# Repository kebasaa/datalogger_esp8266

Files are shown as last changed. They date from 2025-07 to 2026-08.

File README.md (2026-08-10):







# Asynchronous datalogger using ESP8266

Asynchronous datalogger using ESP8266 for logging scientific sensors to MicroSD

## Offline dashboard

The firmware starts a protected setup access point when it has no saved Wi-Fi
credentials and, after a 30-second station outage, exposes the dashboard again
through that access point. Change `HOTSPOT_PASSWORD`, `DASHBOARD_USER` and
`DASHBOARD_PASSWORD` in `src/main.cpp` before deployment.

Open `http://192.168.4.1/` on the access point, or the logger's address on your
network. The dashboard has four tabs:

- **Status** — whether the logger is actually recording, GPS fix and time
  quality, battery, free heap, MicroSD space and write errors, per-bus I2C
  health and the supervisor counters. Updates once a second.
- **Calibration** — sessions, live raw versus calibrated readings, zero/span
  and differential calibration, and the stored coefficients.
- **WiFi** — scan for networks and join one.
- **Console** — runs the same commands as the serial port, for when something
  needs poking at and no cable is to hand.

It is a small single-page app served from the logger's own flash: no internet
connection is needed and nothing is loaded from a CDN. It scales from a phone
in the field to a desktop browser, and follows your system's light or dark
theme (with a toggle to override).

> The web interface lives in `web/src/`. A pre-build script minifies and gzips
> it into `data/h4/`, so after changing it you must upload the filesystem as
> well as the firmware:
>
> ```bash
> pio run -e d1_mini_pro -t upload -t uploadfs
> ```

GPS is connected directly to the I2C bus. Its reader is deliberately separate
from the TCA9548A channels; do not pass the multiplexer to the GPS constructor
unless the hardware wiring changes.

Sensor & logger testing in the field

<p align="center">
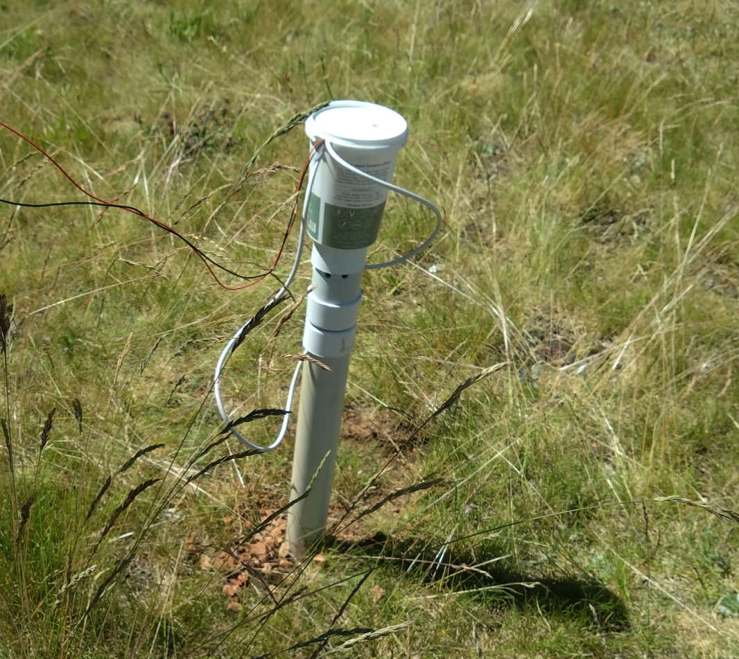
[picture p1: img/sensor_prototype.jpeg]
Prototype testing
  
</p>

## Serial commands

The web interface has no private channel to the firmware: every button on it
runs one of the commands below, over `GET /rest/<command>/<parameters>`. So
anything the dashboard can do can also be done from the serial port or with
`curl`, which is what you want when no Wi-Fi is available, when calibrating
from a script, or when a logger needs rescuing.

### Connecting

Connect at **115200 baud** (`monitor_speed` in `platformio.ini`; the firmware
takes the same value through `PROJ_BAUD_RATE`):

```bash
pio device monitor -e d1_mini_pro
```

Type a command and press Enter. Parameters are separated by a forward slash,
with no spaces:

```
command/parameter/parameter/...
```

Commands are case-sensitive. `help` lists every command the firmware knows,
including the built-in H4 ones described at the end of this section.

### Overview

| Command | Parameters | Needs a session | What it does |
| --- | --- | --- | --- |
| `cal_start` | none | – | Starts a calibration session |
| `cal_stop` | none | yes | Saves everything measured in the session |
| `cal_discard` | none | yes | Throws the session away without saving |
| `cal` | 3–4 | yes | Measures the sensor and calibrates from the reading |
| `set` | 5 | yes | Stores a reference and a measured value entered by hand |
| `show_cal` | none | no | Prints all stored calibration values |
| `cal_reset` | none | no | Clears every stored coefficient (opens and closes its own session) |
| `cal_select` | 2–3 | no | Chooses which quantity and sensor the dashboard's live reading follows |

### Calibration sessions

Calibration values live in flash memory, which wears out if written to too
often. Rather than saving on every calibration, the firmware collects them in a
session and writes them once:

1. `cal_start` — begins recording. Values change in memory only.
2. Any number of `cal` and `set` commands.
3. `cal_stop` — writes everything to flash in a single operation and appends one
   row to `calibration_<date>.csv` on the SD card. The row needs a valid GPS
   date; without a fix the values are still saved to flash, but the log line is
   skipped and `Error: No GPS fix` is printed.

`cal_discard` ends the session and throws the collected values away, leaving
what was previously stored untouched. `cal` and `set` refuse to run outside a
session and answer `Can't do now`, so it is always clear when values reach
flash.

A session that is left open and untouched saves itself after the number of
minutes set by `CALIBRATION_TIMEOUT_MINUTES` in `src/main.cpp` (30 by default,
0 to disable), so a forgotten calibration is not lost. Values collected in an
open session are used immediately for the logged data and are visible to
`show_cal`, but a power cut before `cal_stop` loses them.

The session is shared with the dashboard, because they are the same thing: the
Calibration tab's buttons issue `cal_start`/`cal_stop`/`cal_discard`, so a
session begun over serial is visible in the browser and vice versa.

### Quantity names and units

The quantity is one of the names below. Which ones exist depends on the sensors
enabled in `src/main.cpp`:

| Name | Enabled by | Sensor measures | Reference for `cal/zero` | Reference for `cal/span` | Reference for `set` |
| --- | --- | --- | --- | --- | --- |
| `temperature` | `BME280_BUSES` | °C | °C | °C | °C |
| `pressure` | `BME280_BUSES` | Pa | Pa | Pa | Pa |
| `h2o` | `BME280_BUSES` | mmol/mol | mmol/mol | **dew point in °C** | mmol/mol |
| `co2` | `SCD30_BUSES` | ppm | ppm | ppm | ppm |
| `o2` | `SEN0465_BUSES` | % vol | % vol | % vol | % vol |

Water vapour is the one quantity whose reference is not always in the unit the
sensor reports, because the two calibration points are produced differently. A
span calibration uses a dew-point generator, so `cal/span/h2o/...` takes a **dew
point in °C** and converts it to a mole fraction using the measured air pressure.
A zero calibration uses dry gas, so `cal/zero/h2o/...` takes a mole fraction in
mmol/mol — `cal/zero/h2o/0` with no reference therefore calibrates against dry
air (0 mmol/mol), which is what flushing the sensor with a desiccant or zero air
gives you. `set` never converts anything, so it always expects mmol/mol.

The same split applies to the dashboard: for water vapour the "Zero gas" box is
in mmol/mol and the "Span gas" box is a dew point in °C.

Sensor numbers are **0-based**: with `BME280_BUSES 0, 1` the two sensors are
`0` and `1`. For `cal/zero` and `cal/span`, a sensor number that does not exist
is skipped rather than stored.

### `cal` — measure and calibrate

Takes a reading from the sensor itself and stores it against a known reference.
It averages 10 readings taken about one second apart, so it takes roughly ten
seconds; the command returns immediately and the result appears afterwards.

```
cal/zero/<quantity>/<sensor>
cal/zero/<quantity>/<sensor>/<reference>
cal/span/<quantity>/<sensor>/<reference>
cal/diff/<quantity>/low
cal/diff/<quantity>/high
```

`zero` without a reference uses 0.0. `span` always needs one.

```
cal/zero/co2/1              zero-calibrate CO2 sensor 1 against 0 ppm
cal/zero/co2/1/0.54         zero-calibrate CO2 sensor 1 against 0.54 ppm
cal/span/co2/1/409.87       span-calibrate CO2 sensor 1 against 409.87 ppm
cal/zero/h2o/0              zero-calibrate H2O sensor 0 against dry air (0 mmol/mol)
cal/zero/h2o/0/0.05         zero-calibrate H2O sensor 0 against 0.05 mmol/mol
cal/span/h2o/0/1.31         span-calibrate H2O sensor 0 against a 1.31 °C dew point
cal/span/temperature/0/20.5 span-calibrate temperature sensor 0 against 20.5 °C
cal/diff/co2/low            measure both CO2 sensors at the low concentration
cal/diff/co2/high           measure both CO2 sensors at the high concentration
```

Timing rules the firmware enforces:

- A `span` calibration must follow its `zero` by at least 10 seconds and no more
  than 2 hours, otherwise it is rejected and the reason is printed. Temperature
  is exempt from the 2-hour limit.
- `cal/diff/<quantity>/high` must follow the matching `low` by 10 to 600
  seconds. After 600 seconds only a simple offset is applied instead of a full
  linear correction, and the firmware says so.
- `cal/diff` measures sensors 0 and 1 together and so needs two sensors of that
  type. It takes no sensor number.
- Only one calibration runs at a time; a second one while the first is still
  measuring is ignored.

### `set` — enter values by hand

Stores a reference value and the corresponding sensor reading without measuring
anything. Useful for entering figures from a calibration certificate or from an
earlier session. Requires exactly five parameters.

```
set/<zero|span>/<quantity>/<sensor>/<reference>/<measured>
```

```
set/zero/co2/1/12.07/13.08      sensor 1 read 13.08 ppm when the true value was 12.07
set/span/co2/1/376.87/402.87    sensor 1 read 402.87 ppm when the true value was 376.87
```

Unlike `cal`, `set` ignores the timing rules above, so a `span` can be entered
without a preceding `zero`.

### `show_cal`

Prints every stored calibration value, including values collected in a session
that has not been saved yet. Works with or without a session.

```
show_cal
```

```
Calibration coefficients:
  - sen_co2_0_zero: 13.08
  - sen_co2_0_span: 402.87
  - sen_co2_0_diff: nan
  ...
```

The names read `<sen|ref>_<quantity>_<sensor>_<type>`, where `ref_` is the known
reference value and `sen_` is what the sensor read. For the `diff` type, `ref_`
holds the low value and `sen_` the high one. `nan` means not calibrated.

### `cal_reset`

Clears every stored calibration coefficient, for every quantity and sensor.
This is the "Reset all" button on the Calibration tab. It does not need a
session: if none is open it opens and closes one itself, so the whole reset
costs a single write to flash.

```
cal_reset
```

### `cal_select`

Chooses which quantity and sensor the dashboard's live reading follows. It
changes nothing that gets logged and no calibration depends on it — `cal` and
`set` always take their quantity and sensor as explicit parameters.

```
cal_select/<quantity>/<sensor>[/<differential quantity>]
```

```
cal_select/co2/1
cal_select/co2/1/h2o
```

Until a selection is made the logger does not read a sensor for the dashboard
at all, which keeps the web interface off the I2C bus unless someone is
actually watching a value.

### Worked examples

A full zero and span calibration of one CO<sub>2</sub> sensor, saved in a single
write to flash:

```
cal_start
cal/zero/co2/1                 (flush with zero gas, wait ~10 s for the reading)
cal/span/co2/1/409.87          (flush with 409.87 ppm span gas, at least 10 s later)
show_cal                       (check the values before committing to them)
cal_stop
```

A differential calibration comparing two sensors, where the second run went
wrong and is thrown away:

```
cal_start
cal/diff/co2/low               (both sensors at the low concentration)
cal/diff/co2/high              (both sensors at the high concentration, 10-600 s later)
cal_discard                    (nothing is written; the old values remain)
```

Entering values from a certificate for both sensors:

```
cal_start
set/zero/co2/0/0.0/1.42
set/span/co2/0/400.0/398.15
set/zero/co2/1/0.0/2.07
set/span/co2/1/400.0/403.44
cal_stop
```

### Replies

A command that succeeds prints its own progress messages and nothing else. A
command that fails prints one of these, in addition to a line explaining what
was wrong:

| Reply | Meaning |
| --- | --- |
| `Unknown cmd` | No such command |
| `Too few parameters` | Not enough parameters |
| `Too many parameters` | Too many parameters |
| `Numeric value expected` | A sensor number or reference value was not a number |
| `Incorrect Payload Format` | An unknown quantity, calibration type, or something other than `low`/`high` |
| `Can't do now` | No session open, or a session is already open |

Calibrations rejected by the timing rules are reported as plain text, for
example `<10s since zero calibration. Are you sure the span gas is stable?`.

### Built-in commands

H4, the framework underneath, adds its own commands. Run `help` for the full
list, which depends on how the framework is configured — the reporting commands
(`h4/show/...`) are compiled out in this build, because `H4P_LOG_MESSAGES` is 0.
The ones worth knowing:

| Command | What it does |
| --- | --- |
| `help` | Lists every available command |
| `h4/reboot` | Restarts the logger |
| `h4/clear` | Erases all stored settings, **including every calibration** |
| `h4/factory` | Factory reset; also erases every calibration |

Both `h4/clear` and `h4/factory` delete the file the calibrations live in. Save
anything you need first — `show_cal` prints the values, and every `cal_stop`
appends them to `calibration_<date>.csv` on the SD card.

`h4/factory` is also the way back into access-point mode: it clears the stored
Wi-Fi credentials, so the logger starts its own hotspot on the next boot.
Follow it with `h4/reboot`.

### Over HTTP

Every command above is also reachable at `GET /rest/<command>/<parameters>`,
protected by the same login as the dashboard:

```bash
curl -u admin:datalogger http://<logger-address>/rest/show_cal
curl -u admin:datalogger http://<logger-address>/rest/cal/zero/co2/1
```

The reply is JSON — `res` is 0 on success, and `lines` holds what the command
printed:

```json
{"res":0,"msg":"OK","lines":["Calibration coefficients:","  - sen_co2_0_zero: 13.08"]}
```

Alongside the commands there are a few read-only endpoints the dashboard uses,
which are also handy for scripted monitoring:

| Endpoint | What it returns |
| --- | --- |
| `GET /api/status` | One JSON snapshot of everything on the Status tab |
| `GET /api/events` | The same payload once a second, as a server-sent event stream |
| `GET /api/cal` | Stored calibration coefficients, as JSON |
| `GET /api/wifi/scan` | Networks the logger can see (access-point mode only) |

## Prerequisites
- Requires a GPS module for date, time and location

The following sensors/components are implemented currently:
- [Texas Instruments ADS1115](https://www.ti.com/product/ADS1115) analogue multiplexer
- [Texas Instruments TCA9548](https://www.ti.com/product/TCA9548A) i<sup>2</sup>c multiplexer
- MicroSD card data storage with circular storage buffer
- Analogue battery charge reading (voltage)
- Environmental physics equations
- [Sierra Wireless XA1110](https://source.sierrawireless.com/devices/positioning-modules/xa1110/) GPS module
- [Sensirion SCD-30](https://sensirion.com/products/catalog/SCD30) CO<sub>2</sub> sensor
- [DFRobot SEN0465](https://www.dfrobot.com/product-2510.html) O<sub>2</sub> sensor
- [Bosch BME280](https://www.bosch-sensortec.com/products/environmental-sensors/humidity-sensors-bme280/) air temperature, relative humidity & pressure sensor
- [Melexis MLX90614](https://www.melexis.com/en/product/MLX90614/Digital-Plug-Play-Infrared-Thermometer-TO-Can) thermal radiation sensor
- WIFI & web interface
- Zero, span and differential calibration of every measured quantity, controlled
  from the web interface or the serial port (see [Serial commands](#serial-commands)),
  collected into sessions so a calibration is written to flash only once

To be done:
- Single-bus operation (`I2C_MULTI 0` in `src/config.h`) does not currently
  compile; only the multiplexed dual-bus configuration builds
- When the dashboard pre-fills the "Span gas" box for water vapour it shows the
  stored mole fraction, although the box expects a dew point. Displaying it as a
  dew point needs a mole-fraction-to-dew-point conversion, which
  `lib/Environmental` does not have yet
- Guard the differential-to-absolute conversion against division by zero when
  the two differential calibration points are nearly equal
- The differential check that rejects a high calibration point too close to the
  low one uses a fixed threshold of 100, regardless of the unit of the quantity
  being calibrated
- Cache the calibration coefficients instead of re-reading twelve stored values
  on every conversion, once per second per quantity

## How to Cite

This citation does not work yet. Simply cite the github repository as a website for now:
Muller (2025). *datalogger_esp8266: Asynchronous datalogger using ESP8266*

## License

This software is distributed under the GNU GPL version 3. Any modification of the code in this repository may only be released under the same license, and with attribution of authorship of the original code (i.e., citation above).

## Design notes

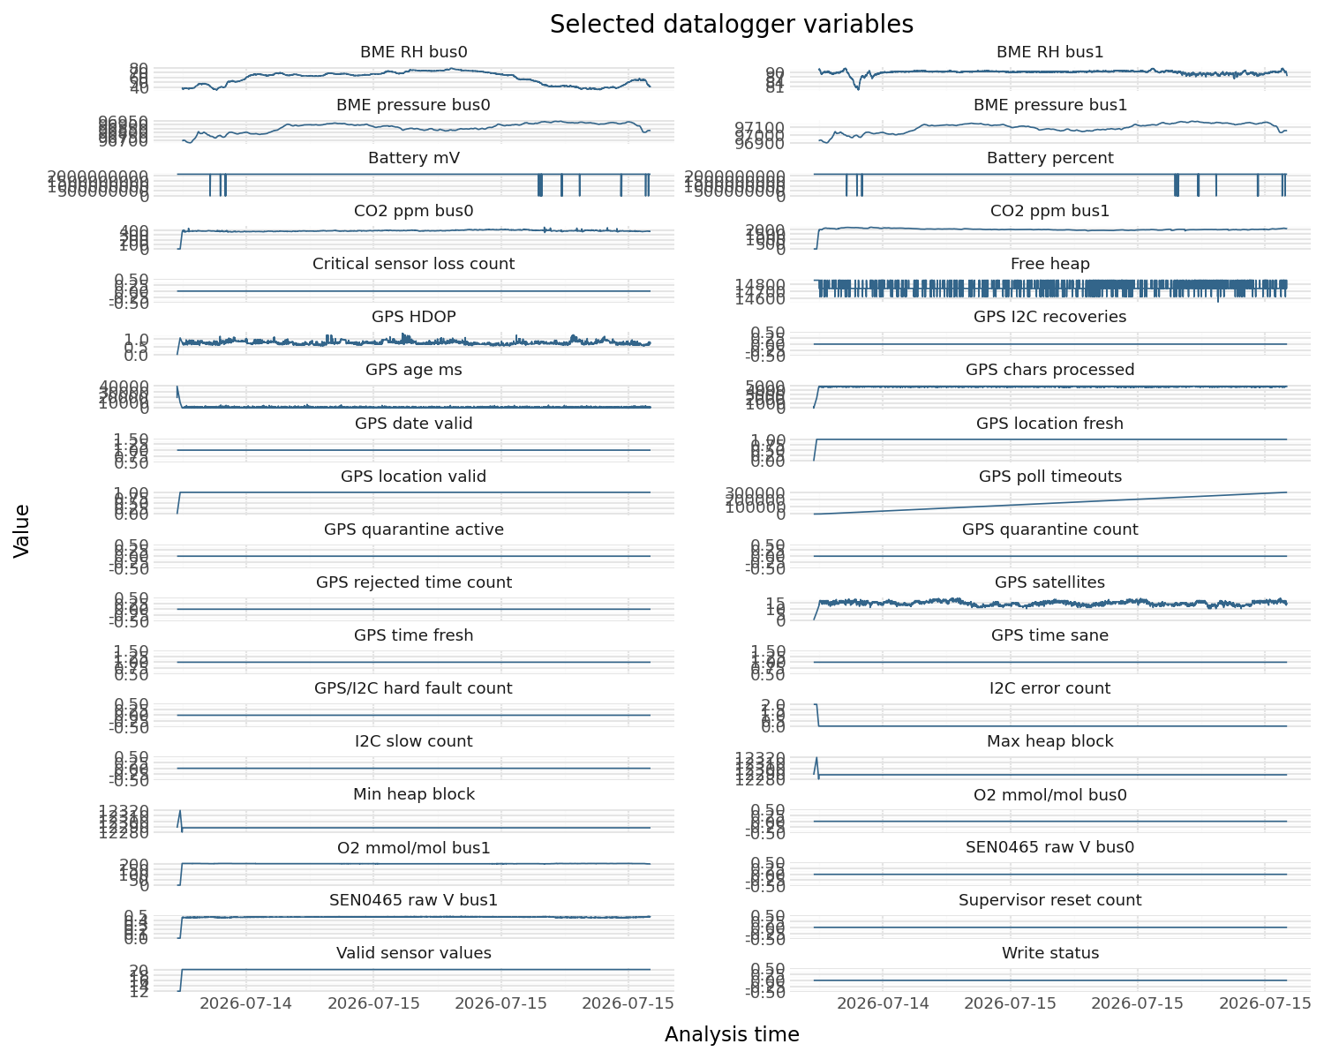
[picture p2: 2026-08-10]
test_analysis/figures/overview_variables.png

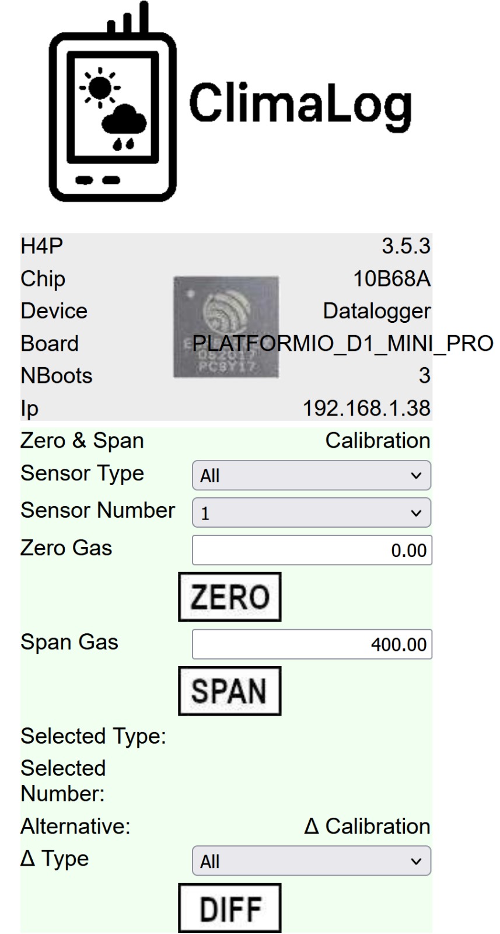
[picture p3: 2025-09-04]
img/screenshot.jpg

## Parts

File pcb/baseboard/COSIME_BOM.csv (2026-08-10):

Reference | Qty | Qty for 3 | Value | stock | Footprint | Datasheet
C1,C2 | 2 | 6 | 1u | M | 603
D1,D5 | 2 | 6 | LED | M | LED_SMD:LED_0805_2012Metric_Pad1.15x1.40mm_HandSolder
D2,D3 | 2 | 6 | BAT54-7-F | M | Diode_THT:D_DO-35_SOD27_P7.62mm_Horizontal | http://www.vishay.com/docs/85622/1n914.pdf
D4 | 1 | 3 | Power-LED | M | LED_SMD:LED_0805_2012Metric_Pad1.15x1.40mm_HandSolder
J1,J2,J3,J4,J5,J6 | 6 | 18 | Screw_Terminal_01x02 | M | SamacSys_Parts1:1839198
J7 | 1 | 3 | Ext_5 | M | SamacSys_Parts1:1778719
J8 | 1 | 3 | Ext_1 | M | SamacSys_Parts1:1778719
J9 | 1 | 3 | Ext_4 | M | SamacSys_Parts1:1778719
J10 | 1 | 3 | Ext_3 | M | SamacSys_Parts1:1778719
J11 | 1 | 3 | Ext_2 | M | SamacSys_Parts1:1778719
J12 | 1 | 3 | Qwiic GPS | M | SamacSys_Parts1:1778719
J13,J14 | 2 | 6 | Soil sensors extension | M | SamacSys_Parts1:1778719
R1,R2,R7,R9,R11,R12,R14,R15 | 8 | 24 | 4.7k | no | Resistor_SMD:R_0603_1608Metric_Pad0.98x0.95mm_HandSolder
R3,R5,R10,R13,R16 | 5 | 15 | 100k | M | Resistor_SMD:R_0603_1608Metric_Pad0.98x0.95mm_HandSolder
R4,R6 | 2 | 6 | 10k | M | Resistor_SMD:R_0603_1608Metric_Pad0.98x0.95mm_HandSolder
R8,R17,R18 | 3 | 9 | 1k | M | Resistor_SMD:R_0603_1608Metric_Pad0.98x0.95mm_HandSolder
SW1 | 1 | 3 | SW_SPDT | M | SamacSys_Parts1:500SSP1S2M2QEA
SW2 | 1 | 3 | Turn_On-Button | M | Button_Switch_SMD:SW_SPST_TL3305A
SW3 | 1 | 3 | User-Button | M | Button_Switch_SMD:SW_SPST_TL3305A
U1 | 1 | 3 |  | M | SamacSys_Parts1:4755 | https://www.digikey.ch/de/products/detail/adafruit-industries-llc/4755/13231325
U2 | 1 | 3 | ESP32-S3-DevKitC | M | PCM_Espressif:ESP32-S3-DevKitC | https://www.mouser.ch/de/ProductDetail/Espressif-Systems/ESP32-S3-DevKitC-1-N32R16V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
U3 | 1 | 3 |  | Eck | SamacSys_Parts1:Pololu_S7V8X | https://eckstein-shop.de/Pololu33VStep-UpStep-DownSpannungsreglerS7V8F3EN
U4 | 1 | 3 |  | BB | SamacSys_Parts1:MSD_BO1_SD-Card_Reader | https://www.berrybase.de/en/micro-sd-card-reader-modul-mit-spi-schnittstelle-kompakt
U5 | 1 | 3 |  | M | SamacSys_Parts1:DS3231_Adafruit | https://www.bastelgarage.ch/rtc-ds3231-zeitmodul-mit-at24c32-eeprom-speicher-32k
U6 | 1 | 3 |  | M | SamacSys_Parts1:TCA9548A_AdaFruit | https://www.bastelgarage.ch/8-kanal-i2c-multiplexer-tca9548asu
U7, U8 | 2 | 6 | FDC6561AN | M | SamacSys_Parts1:SOT95P280X110-6N
U9 | 1 | 3 | FDC658AP | M | SamacSys_Parts1:SOT95P275X110-6N_FDC658AP | https://www.onsemi.com/pub/Collateral/FDC658AP-D.PDF
 | 2 | 6 | PIM411 | M |  | https://www.mouser.ch/de/ProductDetail/Pimoroni/PIM411?qs=vLWxofP3U2xx9uHaO4oUiA%3D%3D
 | 2 | 6 | SCD30 | M
 | 1 | 3 | CR1220 | no | 3V battery

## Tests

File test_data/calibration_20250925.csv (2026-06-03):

timestamp_utc | sen_h2o_1_zero | sen_h2o_1_span | sen_h2o_1_diff | sen_h2o_2_zero | sen_h2o_2_span | sen_h2o_2_diff | sen_co2_1_zero | sen_co2_1_span | sen_co2_1_diff | sen_co2_2_zero | sen_co2_2_span | sen_co2_2_diff | sen_o2_1_zero | sen_o2_1_span | sen_o2_1_diff | sen_o2_2_zero | sen_o2_2_span | sen_o2_2_diff | ref_h2o_1_zero | ref_h2o_1_span | ref_h2o_2_zero | ref_h2o_2_span | ref_co2_1_zero | ref_co2_1_span | ref_co2_2_zero | ref_co2_2_span | ref_o2_1_zero | ref_o2_1_span | ref_o2_2_zero | ref_o2_2_span | CRC16
2025-09-25 19:48:31 | nan | nan | 0.00 | 21474.84 | 0.00 | 0.00 | nan | nan | 0.00 | nan | nan | 0.00 | 21474.84 | 0.00 | 0.00 | 21474.84 | 0.00 | 0.00 | 0.00 | 30.00 | 0.00 | 0.00 | 0.00 | 400.00 | 0.00 | 401.00 | 0.00 | 0.00 | 0.00 | 0.00 | 1808
2025-09-25 19:54:23 | nan | nan | 0.00 | 21474.84 | 0.00 | 0.00 | nan | nan | 0.00 | nan | nan | 0.00 | 21474.84 | 0.00 | 0.00 | 21474.84 | 0.00 | 0.00 | 0.00 | 30.00 | 0.00 | 0.00 | 0.00 | 400.00 | 0.00 | 401.00 | 0.00 | 0.00 | 0.00 | 0.00 | 1ED1
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

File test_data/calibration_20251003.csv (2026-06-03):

timestamp_utc | sen_h2o_1_zero | sen_h2o_1_span | sen_h2o_1_diff | sen_h2o_2_zero | sen_h2o_2_span | sen_h2o_2_diff | sen_co2_1_zero | sen_co2_1_span | sen_co2_1_diff | sen_co2_2_zero | sen_co2_2_span | sen_co2_2_diff | sen_o2_1_zero | sen_o2_1_span | sen_o2_1_diff | sen_o2_2_zero | sen_o2_2_span | sen_o2_2_diff | ref_h2o_1_zero | ref_h2o_1_span | ref_h2o_1_diff | ref_h2o_2_zero | ref_h2o_2_span | ref_h2o_2_diff | ref_co2_1_zero | ref_co2_1_span | ref_co2_1_diff | ref_co2_2_zero | ref_co2_2_span | ref_co2_2_diff | ref_o2_1_zero | ref_o2_1_span | ref_o2_1_diff | ref_o2_2_zero | ref_o2_2_span | ref_o2_2_diff | CRC16
2025-10-03 09:50:24 | nan | nan | nan | nan | nan | nan | nan | nan | nan | nan | nan | nan | nan | nan | nan | nan | nan | nan | nan | nan | nan | nan | nan | nan | 1.00 | 400.00 | nan | 0.00 | 400.00 | nan | nan | nan | nan | nan | nan | nan | 8302
2025-10-03 09:50:24 | nan | nan | nan | nan | nan | nan | nan | nan | nan | nan | nan | nan | nan | nan | nan | nan | nan | nan | nan | nan | nan | nan | nan | nan | 1.00 | 400.00 | nan | 0.00 | 400.00 | nan | nan | nan | nan | nan | nan | nan | 8302
2025-10-03 09:50:45 | nan | nan | nan | nan | nan | nan | nan | nan | nan | nan | nan | nan | nan | nan | nan | nan | nan | nan | nan | nan | nan | nan | nan | nan | 1.00 | 400.00 | nan | 0.00 | 400.00 | nan | nan | nan | nan | nan | nan | nan | C79F
2025-10-03 09:50:45 | nan | nan | nan | nan | nan | nan | nan | nan | nan | nan | nan | nan | nan | nan | nan | nan | nan | nan | nan | nan | nan | nan | nan | nan | 1.00 | 400.00 | nan | 0.00 | 400.00 | nan | nan | nan | nan | nan | nan | nan | C79F
2025-10-03 09:51:06 | nan | nan | nan | nan | nan | nan | nan | nan | nan | nan | nan | nan | nan | nan | nan | nan | nan | nan | nan | nan | nan | nan | nan | nan | 1.00 | 400.00 | nan | 0.00 | 400.00 | nan | nan | nan | nan | nan | nan | nan | AC2F
2025-10-03 09:51:28 | nan | nan | nan | nan | nan | nan | nan | nan | nan | nan | nan | nan | nan | nan | nan | nan | nan | nan | nan | nan | nan | nan | nan | nan | 1.00 | 400.00 | nan | 0.00 | 400.00 | nan | nan | nan | nan | nan | nan | nan | 4559
2025-10-03 09:58:31 | nan | nan | nan | nan | nan | nan | nan | nan | nan | nan | nan | nan | nan | nan | nan | nan | nan | nan | nan | nan | nan | nan | nan | nan | 1.00 | 400.00 | nan | 0.00 | 400.00 | nan | nan | nan | nan | nan | nan | nan | 9AAF
2025-10-03 09:58:52 | nan | nan | nan | nan | nan | nan | nan | nan | nan | nan | nan | nan | nan | nan | nan | nan | nan | nan | nan | nan | nan | nan | nan | nan | 1.00 | 400.00 | nan | 0.00 | 400.00 | nan | nan | nan | nan | nan | nan | nan | 8945
2025-10-03 09:59:13 | nan | nan | nan | nan | nan | nan | nan | nan | nan | nan | nan | nan | nan | nan | nan | nan | nan | nan | nan | nan | nan | nan | nan | nan | 1.00 | 400.00 | nan | 0.00 | 400.00 | nan | nan | nan | nan | nan | nan | nan | B582
2025-10-03 10:10:54 | nan | nan | nan | nan | nan | nan | nan | nan | nan | nan | nan | nan | nan | nan | nan | nan | nan | nan | 0.00 | nan | nan | 0.00 | nan | nan | 1.00 | 400.00 | nan | 0.00 | 400.00 | nan | 0.00 | nan | nan | 0.00 | nan | nan | D00A
2025-10-03 10:10:54 | nan | nan | nan | nan | nan | nan | nan | nan | nan | nan | nan | nan | nan | nan | nan | nan | nan | nan | 0.00 | nan | nan | 0.00 | nan | nan | 1.00 | 400.00 | nan | 0.00 | 400.00 | nan | 0.00 | nan | nan | 0.00 | nan | nan | D00A
2025-10-03 10:11:15 | nan | nan | nan | nan | nan | nan | nan | nan | nan | nan | nan | nan | nan | nan | nan | nan | nan | nan | 0.00 | nan | nan | 0.00 | nan | nan | 1.00 | 401.00 | nan | 0.00 | 400.00 | nan | 0.00 | nan | nan | 0.00 | nan | nan | 54C5
2025-10-03 10:11:36 | nan | nan | nan | nan | nan | nan | nan | nan | nan | nan | nan | nan | nan | nan | nan | nan | nan | nan | 0.00 | nan | nan | 0.00 | nan | nan | 1.00 | 400.00 | nan | 0.00 | 400.00 | nan | 0.00 | nan | nan | 0.00 | nan | nan | 3441
2025-10-03 10:11:57 | nan | nan | nan | nan | nan | nan | nan | nan | nan | nan | nan | nan | nan | nan | nan | nan | nan | nan | 0.00 | nan | nan | 0.00 | nan | nan | 0.00 | 400.00 | nan | 1.00 | 400.00 | nan | 0.00 | nan | nan | 0.00 | nan | nan | FBC1
2025-10-03 10:11:57 | nan | nan | nan | nan | nan | nan | nan | nan | nan | nan | nan | nan | nan | nan | nan | nan | nan | nan | 0.00 | nan | nan | 0.00 | nan | nan | 0.00 | 400.00 | nan | 1.00 | 400.00 | nan | 0.00 | nan | nan | 0.00 | nan | nan | FBC1
2025-10-03 10:12:18 | nan | nan | nan | nan | nan | nan | nan | nan | nan | nan | nan | nan | nan | nan | nan | nan | nan | nan | 0.00 | nan | nan | 0.00 | nan | nan | 0.00 | 400.00 | nan | 1.00 | 401.00 | nan | 0.00 | nan | nan | 0.00 | nan | nan | 5ECD
2025-10-03 15:16:33 | nan | nan | nan | nan | nan | nan | 0.00 | nan | nan | nan | nan | nan | nan | nan | nan | nan | nan | nan | nan | nan | nan | nan | nan | nan | 0.00 | nan | nan | nan | nan | nan | nan | nan | nan | nan | nan | nan | 1FC6
2025-10-03 15:16:55 | nan | nan | nan | nan | nan | nan | 0.00 | 0.00 | nan | nan | nan | nan | nan | nan | nan | nan | nan | nan | nan | nan | nan | nan | nan | nan | 0.00 | 400.00 | nan | nan | nan | nan | nan | nan | nan | nan | nan | nan | CAD2
2025-10-03 15:21:16 | nan | nan | nan | nan | nan | nan | 546.00 | nan | nan | nan | nan | nan | nan | nan | nan | nan | nan | nan | nan | nan | nan | nan | nan | nan | 0.00 | nan | nan | nan | nan | nan | nan | nan | nan | nan | nan | nan | 7D6F
2025-10-03 15:21:16 | nan | nan | nan | nan | nan | nan | 546.00 | nan | nan | nan | nan | nan | nan | nan | nan | nan | nan | nan | nan | nan | nan | nan | nan | nan | 0.00 | nan | nan | nan | nan | nan | nan | nan | nan | nan | nan | nan | 7D6F
2025-10-03 15:21:37 | nan | nan | nan | nan | nan | nan | 546.00 | 0.00 | nan | nan | nan | nan | nan | nan | nan | nan | nan | nan | nan | nan | nan | nan | nan | nan | 0.00 | 400.00 | nan | nan | nan | nan | nan | nan | nan | nan | nan | nan | A4E7
2025-10-03 15:21:37 | nan | nan | nan | nan | nan | nan | 546.00 | 0.00 | nan | nan | nan | nan | nan | nan | nan | nan | nan | nan | nan | nan | nan | nan | nan | nan | 0.00 | 400.00 | nan | nan | nan | nan | nan | nan | nan | nan | nan | nan | A4E7
2025-10-03 15:21:59 | nan | nan | nan | nan | nan | nan | 546.00 | 550.00 | nan | nan | nan | nan | nan | nan | nan | nan | nan | nan | nan | nan | nan | nan | nan | nan | 0.00 | 400.00 | nan | nan | nan | nan | nan | nan | nan | nan | nan | nan | A666
2025-10-03 16:57:28 | nan | nan | nan | nan | nan | nan | 546.00 | 550.00 | nan | 613.00 | 612.00 | nan | nan | nan | nan | nan | nan | nan | nan | nan | nan | nan | nan | nan | 0.00 | 400.00 | nan | 0.00 | 400.00 | nan | nan | nan | nan | nan | nan | nan | 1FA6

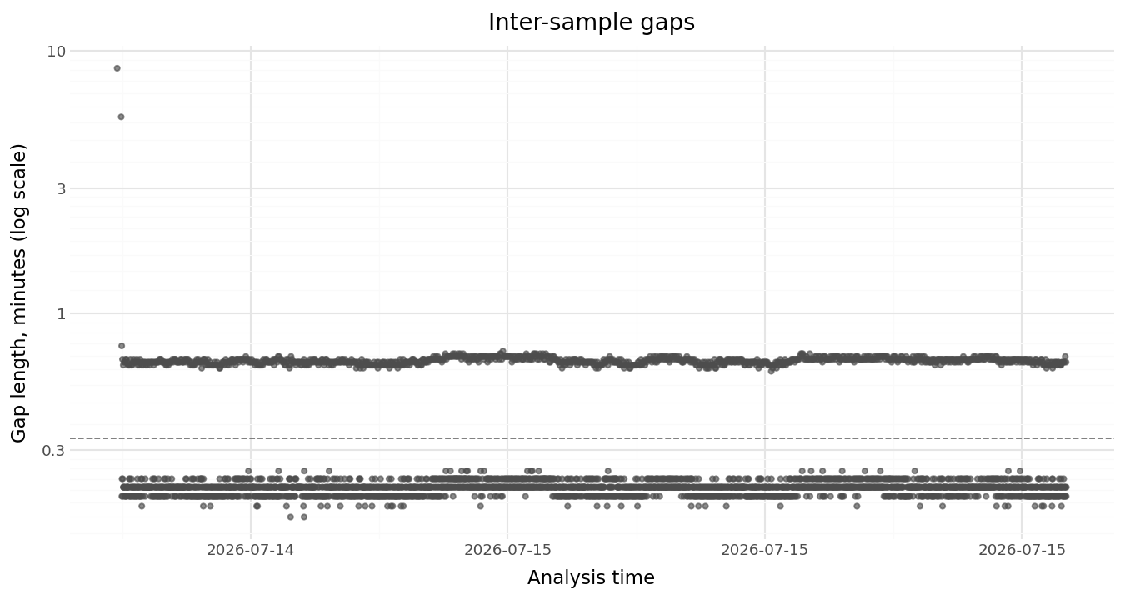
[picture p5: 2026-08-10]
test_analysis/figures/inter_sample_gaps.png

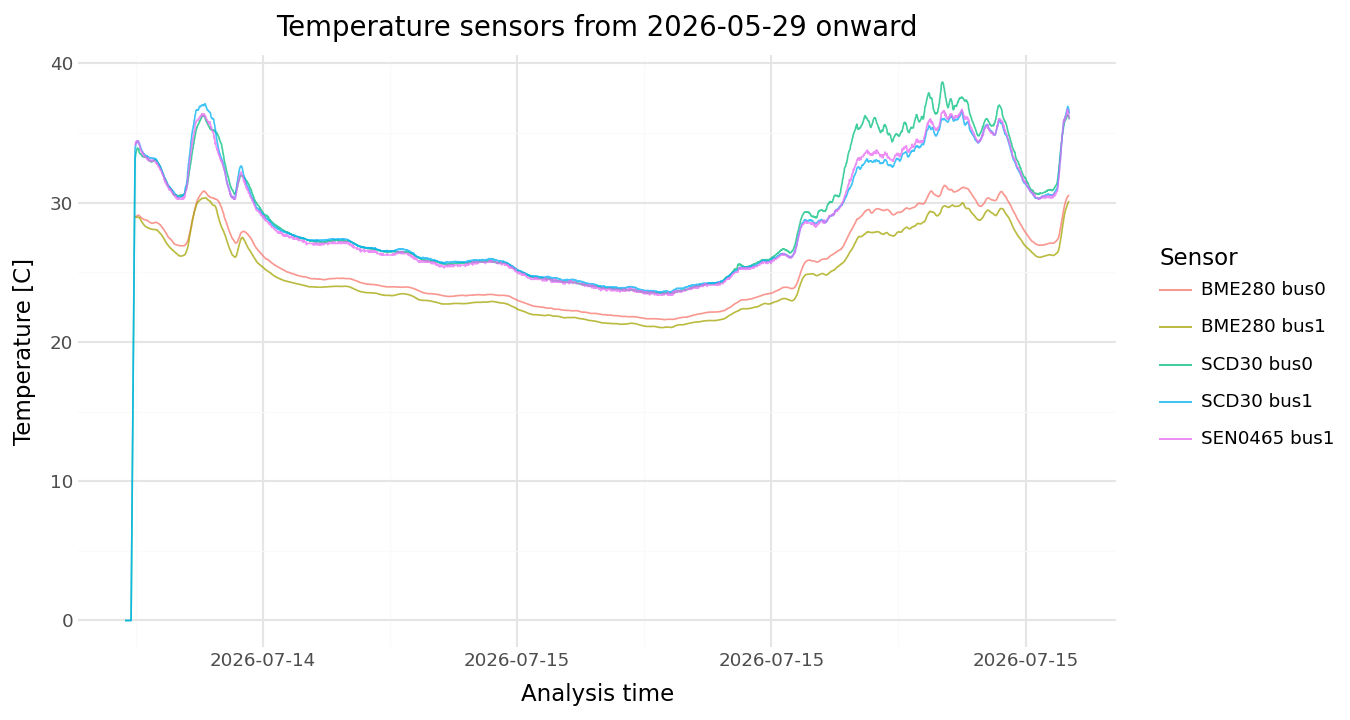
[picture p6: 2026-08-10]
test_analysis/figures/temperature_timeseries.png

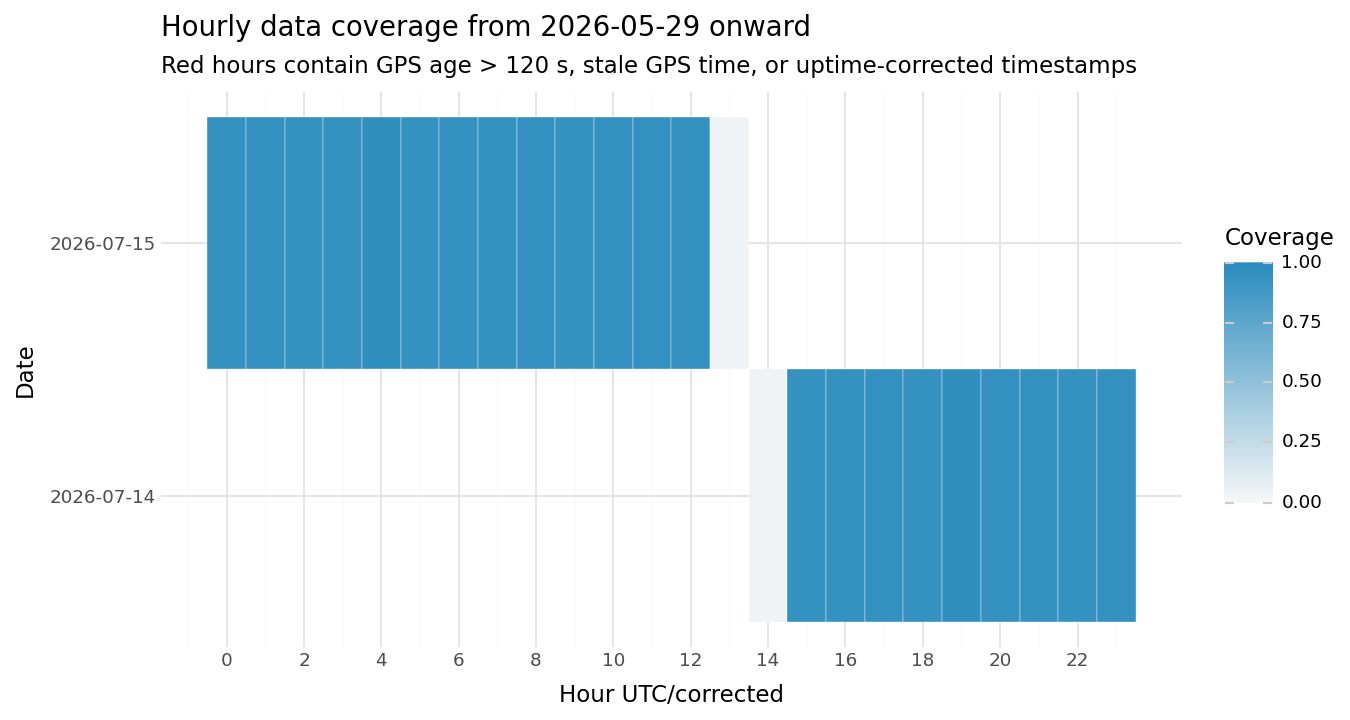
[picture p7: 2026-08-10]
test_analysis/figures/hourly_coverage.png

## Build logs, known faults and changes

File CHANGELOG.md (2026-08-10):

# Changelog

## 0.5

### Calibration values moved out of H4's globals into a checksummed file

Calibration used to live in H4's persistent-globals map, at roughly 120 bytes an
entry — an `unordered_map` node, the name stored twice because `h4proxy` keeps its
own copy of the key, and two heap buffers whenever the name passed the 15-character
small-string limit. A fully calibrated two-sensor logger has **60** of them
(2 dataTypes × 5 quantities × 2 sensors × 3 calTypes), so about **7 KB** — most of
the heap the access point needs. And the `diff` triplet is created automatically by
`fix_all_calibrations()` once both sensors have absolute pairs, so it could not be
avoided by calibrating differently.

Values now live in a fixed `float` array — 240 bytes of static RAM — and are
persisted to `/cal.dat`. The cost is **constant**: measured `Free heap at setup:
14712` with nothing calibrated and `14712` with eight values stored.

The file is **name-keyed, not positional**:

```
sen_co2_0_zero=398.000000
ref_co2_0_zero=400.000000
crc=A31F
```

A positional record would silently shift every value into the wrong slot the day
someone adds a quantity or changes the sensor count. Here an unrecognised name is
ignored and a missing one stays NaN. Only values actually set are written — absent
and `nan` mean the same thing to `read_var()`.

**Power-loss safe.** Writes are staged, never in place: `/cal.new` is written with
a CRC-16, read back and verified, and only then replaces `/cal.dat`. On load the
order is `/cal.dat` → `/cal.new` (what survives a cut between write and rename) →
migrate from H4's globals → all-NaN. A cut at any point leaves either the previous
good file or a complete new one. This is better than before: H4 rewrites the whole
`/glob` in place with no checksum.

**Partial calibration is safe by construction.** `update_var()` writes one array
slot, and commit rewrites the file from the full in-RAM array that was loaded at
boot — so every value not being calibrated is carried through untouched. There is
no read-modify-write for a power cut to catch halfway.

Verified on hardware: calibrated co2 sensor 0, reset, values returned exactly with
everything else `nan`; then calibrated o2 sensor 1 and confirmed co2 sensor 0 was
untouched; `cal_reset` then reported "Reset 8 calibration value(s)", erasing only
what existed.

`purge_placeholder_calibrations()` is gone — nothing seeds placeholders now.
Migration from the old store happens once, in `storage_begin()`.

### The dashboard is reachable: connection leak, single page, no SSE

`H4AsyncWebServer` never closed a server-side connection — the only reclamation
was H4AsyncTCP's 20-second scavenger, against an lwIP built with
`MEMP_NUM_TCP_PCB 5`. Five sockets held 20 seconds each meant a couple of page
loads exhausted the pool, after which lwIP **silently dropped SYNs** (no RST) and
the browser simply timed out. Every response now schedules a deferred close.

The delay is load-bearing. `TX()` only hands lwIP what `altcp_sndbuf()` accepts
right now (`TCP_SND_BUF` = 2 × `TCP_MSS` = 2920) and queues the rest to drain as
ACKs return. The dashboard is ~8.6 KB, so closing a tick later discarded the
remainder and the browser reported `ERR_EMPTY_RESPONSE`.

Alongside that, to cut both connections and heap:

- **One request per page load.** `scripts/build_web.py` now inlines the CSS and JS
  into a single `app.htm.gz`, and the logo and favicon links are gone. Note the
  build must minify the HTML *before* inlining: `minify_html` strips every
  newline while `minify_js` deliberately keeps them, because joining JS lines
  without a parser breaks automatic semicolon insertion.
- **The SSE stream is gone.** `/api/events` held a connection open permanently —
  a fifth of the device's TCP capacity to receive something it could poll for.
  Server-initiated messages now ride on `/api/status` as `msg`/`msgseq`.
- **The stock `/ws` websocket dashboard is no longer built** (`H4P_USE_WS_DASHBOARD`,
  default 0). This project serves its own UI and never opens `/ws`, but the handler
  was still allocated, registered, and keeping the widget list alive.
- **Basic auth applies in station mode only.** In AP mode, making a request at all
  means already knowing the WPA2 password; what it cost was a 401 round-trip on a
  separate socket per page load, and Android opens captive portals in a webview
  that handles basic-auth prompts badly.

Measured idle heap with the AP up, across this work: **7008 → 10104** free,
**4808 → 9688** largest block, against the 7000/3000 that `checkMemory()` requires.

### Captive portal

Android's connectivity probe was reaching the device (DNS is a wildcard) but
getting **401** — the library's file catch-all matches every GET and authenticates,
so the probe never even reached the 404 handler. Android read that as "no internet
access" and never offered to sign in. Probe URLs for Android, iOS, Windows and
Firefox are now registered as unauthenticated 302 redirects, and the DNS pump runs
at 100 ms draining four queries a tick instead of one every 500 ms.

### Fixes

- `H4AW_BasicAuthenticator::authenticate()` built `std::string decoded{dec}` from a
  buffer `base64_decode_block` never NUL-terminates, reading stack garbage — so
  correct credentials were rejected non-deterministically. Now constructed with the
  known length.
- The 401 was sent with no body and therefore no `Content-Length`
  (`send()` only emits it when length is non-zero), delimited solely by a
  synchronous `close()` that made lwIP emit RST instead of FIN. It now has a body,
  and `_reset()` is called on the auth-failure path — without it the handler
  singleton kept `WWW-Authenticate`, `Connection: close` and `Content-Length`
  forever, and the next response went out with both `Content-Length` and
  `Transfer-Encoding: chunked`.
- `h4t::readFileChunks()` called `malloc` and wrote to the buffer **without a NULL
  check**, so a failed allocation wrote to address 0 and rebooted the device
  mid-response. `dl_send_static()`'s own per-chunk `malloc` is gone too — `TX()`
  copies by default, so it was allocating ~1.4 KB twice per chunk.
- `H4AT_DEBUG` and `H4T_DEBUG` were `#define`d unguarded, so `-D` on the command
  line was silently overridden and `-w` hid the warning. Both are now
  `#ifndef`-guarded. They are off by default: measured at +3.3 KB of static RAM,
  which took free heap below H4AsyncTCP's own accept threshold — enabling them
  broke the thing they were meant to diagnose.
- `H4P_WiFi::_ws` was uninitialised while `_sendWS()` tested `if(_ws && ...)`.
- H4Tools had no patch file at all; edits to it would have vanished on the next
  clean build. Added `h4tools.patch` and registered it in `scripts/patch_h4.py`.

### Only real calibrations are stored, which is what made the access point usable

Earlier firmware seeded every calibration variable with `nan` at boot — about 66
of them on a two-sensor logger — and reloaded the lot from LittleFS before
`setup()` even started. That bought nothing: `Cal::read_var()` already returns
NaN for a variable that does not exist, by the same path it returns NaN for one
holding `"nan"`. What it cost was heap, and on an ESP8266 running a Wi-Fi access
point there was none to spare. Each entry is a ~22-character key (past the
small-string limit, so a heap allocation of its own) plus its value and a map
node.

Measured on the bench, and this is why the access point could not hand out DHCP
leases:

| | before | after |
|---|---|---|
| free heap at setup | 7096 | **14400** |
| free heap after init | 6440 | **13744** |
| free heap with the AP up | 1760 (largest block 1064) | **9064** (largest block 8680) |

At 1760 bytes free with a 1064-byte largest block, the SDK could not accept a
station association at all — the AP heartbeat showed `stations=0` permanently,
so the phone never even got as far as DHCP. The reported symptom was "IP
configuration failed"; the actual cause was that there was no memory to associate
with.

`init_all_calibrations()` is replaced by `purge_placeholder_calibrations()`,
which deletes any calibration entry that decodes to NaN and reports how many went.
`reset_all_calibrations()` now deletes rather than writing `nan` back, for the
same reason. Both batch into a single flash write via the new `Cal::erase_var()`,
because H4's `gvErase()` rewrites the whole persistent file once per call.

**The read path is unchanged, and is safe against a missing entry by two
independent layers:** `Cal::read_var()` checks the in-session `_pending` map,
then does an explicit `if(!h4_gvExists(name)) return float(NAN);` *before* it ever
calls `h4_gvGetString`; and `decode_cal_value("")` returns NaN as well. Note
`h4_gvExists` is a real lookup, not `h4p[name]` — the latter creates an empty
variable just by reading it, which is exactly the hazard here, and is why
`h4_gvSetSave()` has been guarded that way all along.

Verified on hardware: all 60 entries read back `nan` (never `0`, never empty,
never stale); `cal_start` → `set/zero/co2/0/400/398` → `cal_stop` → reset →
`sen_co2_0_zero: 398.00` and `ref_co2_0_zero: 400.00` came back exactly, with
every other entry still `nan`; `cal_reset` then reported "Reset 2 calibration
value(s)", erasing only the two that existed.

### Access point crash-loop fixed: WiFi scanning is now on demand only

`_startAP()` armed `h4.every(H4P_AP_SCAN_RATE, scan)` — a full-band WiFi scan
every 5 seconds, for as long as the access point was up, with nothing to stop it.
On the ESP8266 that is fatal in two independent ways:

1. `WiFi.scanNetworks()` calls `WiFi.enableSTA(true)`, so the interface never
   really stayed in `WIFI_AP`. It flipped to `WIFI_AP_STA` and walked every
   channel, leaving the AP's own channel for roughly 1.5–2.5 s out of every 5 s.
   `_startScan()` also ran *before* `WiFi.mode(WIFI_AP)`, so the first scan was
   aborted by the mode change and guaranteed an immediate re-scan.
2. On completion the core's `ESP8266WiFiScanClass::_scanDone()` heap-allocates
   the result array (sized by the number of networks found). This firmware does
   not have that much contiguous heap spare, the allocation threw, and the
   unhandled OOM panicked the device.

Measured on the bench: the device rebooted every ~12 s, five times a minute,
with `last failed alloc call: 4022A9B1(1120..1840)`. The access point therefore
existed for about 7 seconds at a time, which is why a phone could see the
hotspot but never finish auth → assoc → 4-way handshake → DHCP. The reported
symptom was "can't get an IP address"; the actual cause was that the AP kept
vanishing mid-handshake.

Scanning is now one-shot and starts only on an explicit user request
(`GET /api/wifi/scan`, behind the WiFi tab's "Search for WiFi networks" button).
The result array is released with `WiFi.scanDelete()` as soon as it is copied,
and a scan is refused outright when the largest free block is under
`H4P_SCAN_HEAP_FLOOR`, so a low-memory moment reports "not enough memory to scan"
instead of panicking. `WiFi.softAP()`'s return value is now checked too — it
returns false without configuring anything if the PSK is outside 8–64
characters, and that was previously silent.

New patch hunks: `ap_scan_on_demand`, `ap_no_background_scan`, `ap_start_check`.

### I2C: a stuck bus is detected instead of stalling the boot

Every sensor failed to initialise, including the XA1110 GPS, which sits on the
raw bus and never touches the multiplexer — so the bus itself was dead, not the
mux. The boot timings showed what: the multiplexer failed in 36 ms, the GPS in
3.0 s, each BME280 in ~6.3 s. An absent device NACKs in microseconds, so
multi-second failures meant every bit-wait was running to the full clock-stretch
limit, i.e. **SCL was being held low**. Total boot time was ~53 s.

A soft reset resets the ESP but not its I2C slaves, so a slave left mid-transfer
by an earlier reset keeps holding the bus across every subsequent reboot. Only
removing power clears it, which is exactly what fixed it on the bench.

- `dl_i2c_bus_recover()` pulses SCL up to 9 times to clock a slave off the bus
  and issues a STOP. It reports failure when SCL itself is held low, since a
  master cannot recover that.
- `dl_i2c_bus_reset()` runs that, re-inits the peripheral and restores the
  clock-stretch limit. It is called once at boot before probing anything, and
  from `recoverI2C()`, which now also re-runs `mp.init()` — a glitched
  multiplexer was never being re-initialised.
- When the bus is stuck, sensor probing is **skipped** rather than attempted.
  Boot drops from ~53 s to under 1 s and says `STUCK (SCL held low —
  power-cycle the logger)` instead of printing eight identical `Failed` lines.

`I2C_CLOCK_STRETCH_US` is now 200 ms, not 2 ms. The old 2 ms value was never
actually in force — the GPS, SEN0465 and MLX90614 drivers each call
`Wire.begin()` from their own `init()`, and `twi_init()` resets the limit to the
150 ms core default every time — and enforcing it would have broken the SCD30,
which legitimately stretches SCL for tens of milliseconds and whose own driver
sets 200 ms. A stuck bus is now handled by detecting it, not by truncating
legitimate stretching. The limit is re-applied after the last sensor `init()`
and after every recovery, so it no longer depends on which driver ran last.

### Fixes

- `GPS::update_values()` returns early unless `init()` has run. `I2CGPS::begin()`
  assigns its `_i2cPort` before probing, so a *failed* GPS init still left a
  usable object, but *skipping* init (stuck bus) left it null and the 250 ms poll
  timer dereferenced it — Exception (28) every 3 s.
- `MULTI::init()` called `mp.begin(addr)`, but `TCA9548::begin()` takes a
  **channel mask**, not an address (the address comes from the constructor).
  Passing `0x70` enabled channels 4, 5 and 6 simultaneously, bridging three mux
  segments onto the bus until the disable loop ran. Now `mp.begin(0x00)`.
- `MULTI::_currently_active_bus` was a `uint8_t` initialised to `9999`, which
  truncates to 15. Every comparison against `9999` was therefore wrong:
  `disableCurrentBus()` could never fire. Replaced with `MULTI_NO_BUS` (`0xFF`).
  The narrowing warning that would have caught this is suppressed by `-w`.
- The boot banner printed `WiFi.localIP()` even in AP mode, where it is the
  unused station address and renders as `(IP unset)` — it reads like a failure.
  It now prints `softAPIP()` when in AP mode, plus free heap and largest free
  block at setup entry and after init.
- `H4P_WiFi::_lostIP()` called `_coreStart()` — which runs `_startAP()` and with
  it `_startWebserver()` — and then `_stopWebserver()` on the very next line, so
  the access point was left with no webserver at all. `_startAP()` early-returns
  on `if(_dns53) return`, so nothing ever started it again. `_stopWebserver()` is
  for losing a *station* connection; it is now skipped when `_coreStart()` has
  just brought the AP up (`ap_keep_webserver` hunk).
- The `softAP()` failure check and the scan-refusal message added with the
  scanner rework used `H4P_PRINTF`, which expands to nothing unless `H4P_DEBUG`
  is set — so an access point that failed to start would have said nothing at
  all. Both now use `_H4P_PRINTF`, and the AP start logs
  `AP UP: SSID=… IP=…` unconditionally.

### H4 dependency stack updated

All seven H4 libraries move together, since they are released and tested as a
set:

| Library | Was | Now |
| --- | --- | --- |
| H4 | 4.0.7 | 4.0.10 |
| H4Tools | 0.0.14 | 0.0.16 |
| H4AsyncTCP | 0.0.23 | 0.0.25 |
| H4AsyncMQTT | 1.0.0-rc11 | 1.0.0-rc12 |
| ArmadilloHTTP | 0.1.8 | 0.2.0 |
| H4AsyncWebServer | 0.0.10 | 0.0.13 |
| H4Plugins | 3.5.3 | 3.5.8 |

This is the combination h4plugins 3.5.8 pins in its own `platformio.ini`, which
is the set upstream CI builds every example against — including an ESP8266
target on the same platform and build flags used here. Only the versions were
taken from that file; none of its build settings were adopted. ArmadilloHTTP is
the single deviation, at 0.2.0 rather than the 0.1.9 upstream tests.

Two of the old pins were **below h4plugins' own declared minimums**
(`H4Tools>=0.0.16`, `H4AsyncWebServer>=0.0.12`), so this is a correctness fix
rather than housekeeping. H4AsyncWebServer 0.0.11 also fails to compile on a
case-sensitive filesystem — `H4AT_HTTPHandlerWS.cpp` included
`<H4ASyncWebServer.h>` with the wrong capitalisation, fixed in 0.0.13.

**Never pin h4plugins 3.5.6.** Its `H4P_Timekeeper.cpp` calls `LOCK_TCPIP_CORE()`
unconditionally, which does not exist on the ESP8266, so it does not build for
this board at all. 3.5.7 added the missing no-op fallback and it is intact at
3.5.8.

Beyond that, these releases are almost entirely the CC BY-NC-SA to MIT
relicensing, which rewrites the header comment of nearly every file and makes
the diffs look far larger than they are. The substantive code changes across the
whole set are: `#ifndef` guards around tuning macros in H4 and h4plugins (with
`SANITY` renamed to `H4P_SANITY` — unused here), a missing `#include <algorithm>`
and a member-initialiser order fix in H4Tools, one added method in ArmadilloHTTP,
and the include-case fix above. Flash and RAM usage came out byte-identical to
the previous build, which is the expected result.

All five patches were re-derived against the new revisions. Of the 30 hardening
changes, 28 carried over unchanged and two were retired:

- `tcp_scavenge_guard` — fixed upstream in H4AsyncTCP 0.0.25.
- `ap_dashboard` — it populated the old widget dashboard's system panel, and
  that dashboard no longer exists.

One hunk needed a real merge rather than a mechanical one. 3.5.6 added a guard
to `_gotIP()` that returns early when the address is `0.0.0.0` ("prevents fake
gotIP event"). Our access-point teardown now runs **after** that guard: running
it before would tear down the captive portal on a spurious event and strand
whoever was connected to it.

Also worth knowing: 3.5.6 changed the library's own default for
`H4P_USE_WIFI_AP` from 0 to 1, which is upstream independently noticing the
problem described in the next section. The fix below is still required — a user
choosing `WIFI_ACCESS_POINT_MODE 0` would otherwise still be ignored — and it
makes the value explicit rather than inherited from a default.

`scripts/patch_h4.py` now checks the version it finds on disk against the
version each patch was derived against, and stops with a clear message when they
disagree. Previously the version strings were used only in error text, so a
moved pin surfaced as a context mismatch naming the wrong revision. The check
reads the Git tag rather than `library.properties`, because upstream repeatedly
ships releases without bumping that file — H4AsyncWebServer 0.0.11 declares
0.0.10, and ArmadilloHTTP 0.2.0 declares 0.1.9.

**After updating, delete `.pio/libdeps/d1_mini_pro` once** so the new
dependencies are fetched and the re-derived patches apply to clean trees.

### Access-point mode was never actually compiled in

`H4P_USE_WIFI_AP` and `DATALOGGER_AP_PASSWORD` were defined in
`src/dl_config_map.h`, a project header. PlatformIO compiles H4Plugins' own
`.cpp` files as separate translation units that never include a project header,
so the library was built with its default of `H4P_USE_WIFI_AP 0`: the compiled
firmware contained no `_startAP`, no `_apViewers` and no network scanner, and
the AP-password hunk in `scripts/patches/h4plugins.patch` had nothing to apply
to. Had the access point started, it would have been open.

The macro also guards a data member of `class H4P_WiFi` (the captive-portal
`DNSServer`), so the project and the library disagreed about the layout of the
same class — undefined behaviour, not just a missing feature.

- New pre-build script `scripts/project_defines.py` reads those two settings
  out of `src/main.cpp` and passes them as global `-D` flags, so the project and
  its libraries are built from the same values. `src/main.cpp` stays the only
  file to edit.
- `src/dl_config_map.h` now defers to those flags instead of defining the
  macros itself.

### New web interface

The stock H4Plugins widget dashboard has been replaced by a single-page app
served from the logger's flash. The old one was locked to a 300 px column, used
paired JPEGs as buttons, and could only show the fixed set of widget types the
framework provides — which is why nothing but calibration was ever on it.

- Four tabs: **Status** (recording state, GPS quality, battery, heap, MicroSD,
  per-bus I2C health, supervisor counters), **Calibration**, **WiFi**, and a
  **Console** that runs any serial command.
- Responsive from a 320 px phone to a desktop, follows the system light/dark
  theme with a manual override, and uses real buttons instead of images.
- Live values arrive over server-sent events at `/api/events`, falling back to
  polling `/api/status` if the stream drops.
- New read-only endpoints `/api/status`, `/api/cal` and `/api/wifi/scan`, and
  `POST /api/wifi/connect` for provisioning.
- Sources live in `web/src/`; `scripts/build_web.py` minifies and gzips them
  into `data/h4/`. It fails the build if an asset exceeds the size the device's
  TCP send buffer can absorb without queueing it on the heap.
- The legacy assets are gone (`sta.htm`, `h4.css`, `h4.js` and 18 JPEGs),
  freeing about 54 KB of the filesystem. This also retires a latent bug: the
  dashboard's "discard" button referenced `discard0.jpg`/`discard1.jpg`, which
  never existed, so it always rendered as a broken image.

**After updating, upload the filesystem as well as the firmware**
(`pio run -t upload -t uploadfs`); otherwise the logger has no web interface to
serve.

### Calibration is now entirely command-driven

The dashboard used to drive calibration through framework global variables that
only its widgets could set, so several things were possible in the browser and
not over serial. Every action is now a command, and the web interface calls
those commands over `/rest`.

- New `cal_reset` command, the old "reset" button. Clears every stored
  coefficient in a single write to flash.
- New `cal_select` command, replacing the two dashboard dropdowns. It only
  chooses which reading the dashboard displays; no calibration depends on it.
- `cal/zero` and `cal/diff` accept `all` as the quantity, which the old
  dropdown offered but the command did not. `cal/span/all` is rejected with an
  explanation rather than silently doing nothing.
- Messages go to whichever channel asked for the work: the serial port always,
  the `/rest` reply when the request came over HTTP, and the browser as a
  notification.

### Framework fixes

Three hunks added to `scripts/patches/h4plugins.patch`:

- `H4P_WiFi::_rest` cleared its reply buffer only *after* building a response,
  and the websocket console never cleared it at all, so output from one command
  was replayed in later responses.
- `H4P_WiFi::change()` guarded its reboot with `H4P_WIFI_USE_AP`, a macro
  defined nowhere in the tree (the real one is `H4P_USE_WIFI_AP`), so changing
  the Wi-Fi credentials from a command never rebooted out of access-point mode.

`scripts/patches/README.md` gains the two workflows it was missing —
regenerating a patch, and upgrading a pinned upstream version — and no longer
renders every code block as literal backslashes.

Existing checkouts need `.pio/libdeps/d1_mini_pro/H4Plugins` deleted once so the
updated patch applies to a clean tree.

### Calibration sessions

Calibrating used to write to flash on every button press, and each write
rewrote the whole stored-settings file. Calibration now happens inside a
session: switch "Calibration mode" on in the dashboard, do as many zero, span
and differential calibrations as needed, then switch it off to save them all in
a single write. A "discard" button throws the session away without writing
anything, and the calibration log on the SD card gains one row per session
instead of one per span and per differential-high calibration. Seeding a fresh
logger dropped from one write per stored value to one in total.

- New setting in `main.cpp`: `CALIBRATION_TIMEOUT_MINUTES` (default 30). A
  calibration left switched on and untouched for this long saves itself so the
  work is not lost; 0 disables that.
- New serial commands `cal_start`, `cal_stop` and `cal_discard`, the equivalent
  of the dashboard switch. The existing `cal` and `set` commands now require a
  session, so it is always clear when values reach flash.
- Air pressure is a fully supported calibration quantity: it is initialised,
  reconstructed, reset and logged like the others, and appears in the zero/span
  selector rather than only in the differential one. The variable holding the
  list was renamed from `gases` to `quantities`, since it also holds temperature
  and pressure.

### Calibration correctness fixes

- Calibration values are stored as plain decimal numbers instead of the value
  multiplied by 100000 in a 32-bit integer. The old encoding could not represent
  anything above 21474, so calibrating air pressure (about 101325 Pa) silently
  stored a meaningless number. Values written by older firmware are still read
  correctly and are converted the next time they are written.
- A stored value of -0.09999 is no longer mistaken for "not calibrated".
- Zero-calibrating water vapour now calibrates against dry air. The reference
  value was previously read as a dew point for both calibration points, so a
  zero calibration with the default reference of 0 was interpreted as a dew point
  of 0 °C, about 6 mmol/mol, rather than as dry air. The span point still takes a
  dew point in °C, since that is what a dew-point generator is set to; the zero
  point now takes a mole fraction in mmol/mol, since it is produced with dry gas.
- The "set span" button read the reference value out of the *Zero gas* box, so
  whatever was typed into *Span gas* was ignored.
- The check for a calibration that ran across midnight never triggered, because
  it compared unsigned times and so could never see a negative interval. A span
  calibration just after midnight was rejected as being more than two hours
  after the zero calibration. The differential version of the same check added a
  day to the wrong variable and then let the interval bypass both stability
  checks entirely.
- The reference value typed into the dashboard is validated before use. An empty
  box previously crashed the logger, and a box showing "nan" stored a
  meaningless reference.
- Calibrations rejected for timing reasons now say so in the dashboard and on
  the serial port instead of failing silently while the display still showed the
  measured numbers.
- The once-a-minute pass that reconstructs missing calibration values no longer
  runs while a calibration is in progress, where it could overwrite values
  between the measuring and the storing step.
- Fixed builds with `ENABLE_GPS 0` and `ENABLE_MICROSD 1`, which failed to
  compile. Without a GPS there is no wall clock, so calibration timing checks
  now measure from power-on; they only ever compare two such times.

### Datalogger stability and offline operation

- GPS is initialized directly on its I2C bus rather than through multiplexer
  channel 2. This prevents GPS transactions from being disrupted by
  multiplexer selection or reset activity.
- GPS recovery no longer resets the global I2C or multiplexer state. GPS
  faults are handled locally, reducing the chance that recovery interrupts
  otherwise healthy sensors.
- GPS processing is time-sliced through H4 instead of allowing a long
  parse/read operation to monopolize the ESP8266 loop. Each slice is bounded
  to 20 ms or 64 characters and runs every 250 ms, keeping Wi-Fi, the web UI,
  MQTT, and sensor timers responsive during NMEA bursts.
- The ESP8266 I2C clock-stretch limit is configured for the GPS path, reducing
  failures from devices that temporarily hold SCL low and bounding the impact
  of a stuck I2C device.
- Enabled fallback Wi-Fi AP mode. The normal dashboard remains available
  offline, with Wi-Fi provisioning controls and the configured AP password.
- Web UI authentication is no longer coupled to TLS-only configuration. HTTP
  basic authentication protects both station and fallback-AP dashboard access.

Together, these changes isolate the most lockup-prone device, prevent GPS
recovery from causing collateral I2C failures, and make the H4 event loop more
predictable under bad GPS or network conditions.

### H4 dependency hardening

These patches harden the pinned H4 networking stack without changing normal
application-facing APIs.

#### H4Plugins

- Prevent crashes from blank serial commands, empty REST output, empty MQTT
  report lists, and empty MQTT topic strings.
- Improve AP fallback lifecycle: avoid duplicate AP/DNS startup; retain and
  cancel the DNS timer; stop stale scans; and clean DNS state on Wi-Fi
  reconnection.
- Keep the normal dashboard available in offline AP mode and add Wi-Fi
  provisioning controls.
- Support the configured AP password.

#### H4AsyncWebServer

- Reject malformed or empty HTTP request lines safely.
- Validate `Content-Length`, prevent oversized or truncated body handling, and
  check allocations before copying request data.
- Avoid indexing malformed query or form parameters.
- As a result, hostile or broken browser/TCP input returns a safe error rather
  than corrupting memory or crashing.

#### ArmadilloHTTP

- Use bounded header detection instead of unbounded string searching on raw
  TCP buffers.
- Safely reject incomplete or malformed HTTP responses and guard response
  reassembly.
- This reduces failures caused by partial network packets or bad upstream
  responses.

#### H4AsyncTCP

- Validate split URL components before accessing them.
- Malformed URLs therefore no longer risk vector-index crashes.

#### H4AsyncMQTT

- Validate receive-frame presence and length before accessing packet bytes.
- Malformed or empty MQTT packets are rejected safely.

### H4 dependency resource and safety fixes

A second round of patches to the pinned H4 stack, targeting correctness bugs and
ESP8266 resource waste found by a code audit. All edits are internal to the
libraries; no application-facing API changes, so the datalogger's calls are
unchanged. Edits are tagged `// H4HARDEN:` (bug/safety) or `// H4PERF:` (waste).

#### H4AsyncTCP

- Fix a shadowed local `_scavenging` that defeated the scavenger guard, so every
  socket shutdown re-queued a full connection scavenge (heap-allocating task plus
  a walk of all connection sets). The guard now works and scavenges are queued
  once per cycle. (`tcp_scavenge_guard`)
- Skip the per-accept/connect/shutdown connection walk in `checkPCBs` when debug
  is off — it only fed a compiled-out debug print. (`tcp_checkpcbs_debug_only`)

#### H4AsyncWebServer

- Validate WebSocket frame length before indexing the header, extended-length,
  mask and payload bytes; short or crafted frames are rejected instead of
  over-reading the receive buffer. (`ws_frame_bounds`)
- Guard the SSE `onChange` callback so an unset handler no longer calls an empty
  `std::function` (which would abort). (`sse_cbconnect_guard`)

#### H4AsyncMQTT

- Fix a stray semicolon that made the QoS2 once-only dispatch unconditional, so a
  re-sent (DUP) QoS2 PUBLISH was delivered to the user twice. (`mqtt_qos2_dedup`)
- Clamp the wire length prefix in `mqttTraits::_decodestring` to the packet
  buffer so malformed inbound strings degrade gracefully instead of over-reading.
  (`mqtt_decodestring_bounds`)

#### H4Plugins

- Guard an out-of-bounds `parts[1]` read in the `config` command parser when a
  token has no `=`. (`cfg_parts_bounds`)

### Patch installation

- Added portable per-library Git patches in `scripts/patches/` and the
  `scripts/patch_h4.py` pre-build installer.
- The installer applies all changes reproducibly from standard Git patch
  files, detects exact already-applied patches without reapplying them, and
  refuses unknown modified dependency trees.
- Recognized caches created by the retired inline patcher are reset and
  re-downloaded before the portable H4Plugins patch is applied. Windows
  file-lock retries make that cleanup resilient to temporary Git or indexer
  locks.

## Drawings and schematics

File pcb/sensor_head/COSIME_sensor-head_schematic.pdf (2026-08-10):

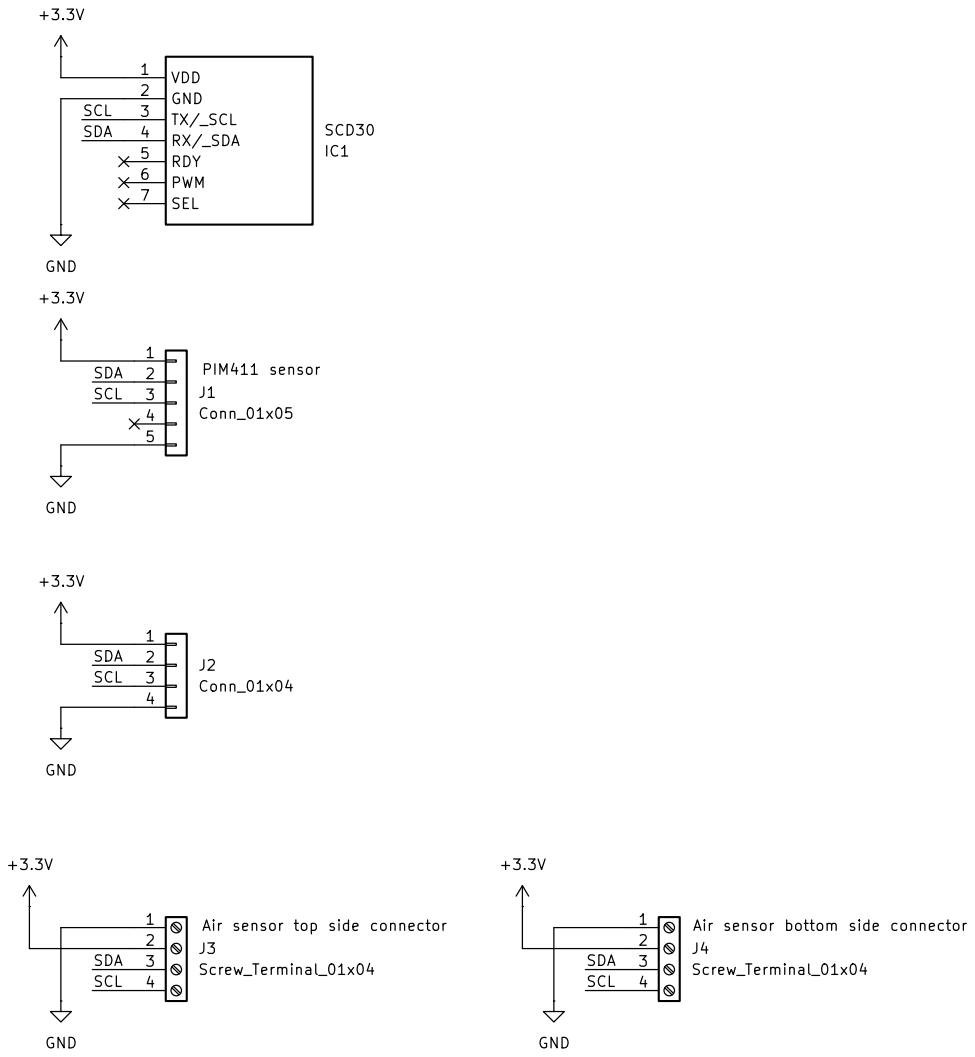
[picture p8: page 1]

Grassland Sciences Group
Institute for Agricultural Sciences
ETH Zürich

Size: A4 | Rev: A
KiCad E.D.A. 10.0.3 | Id: 1/1

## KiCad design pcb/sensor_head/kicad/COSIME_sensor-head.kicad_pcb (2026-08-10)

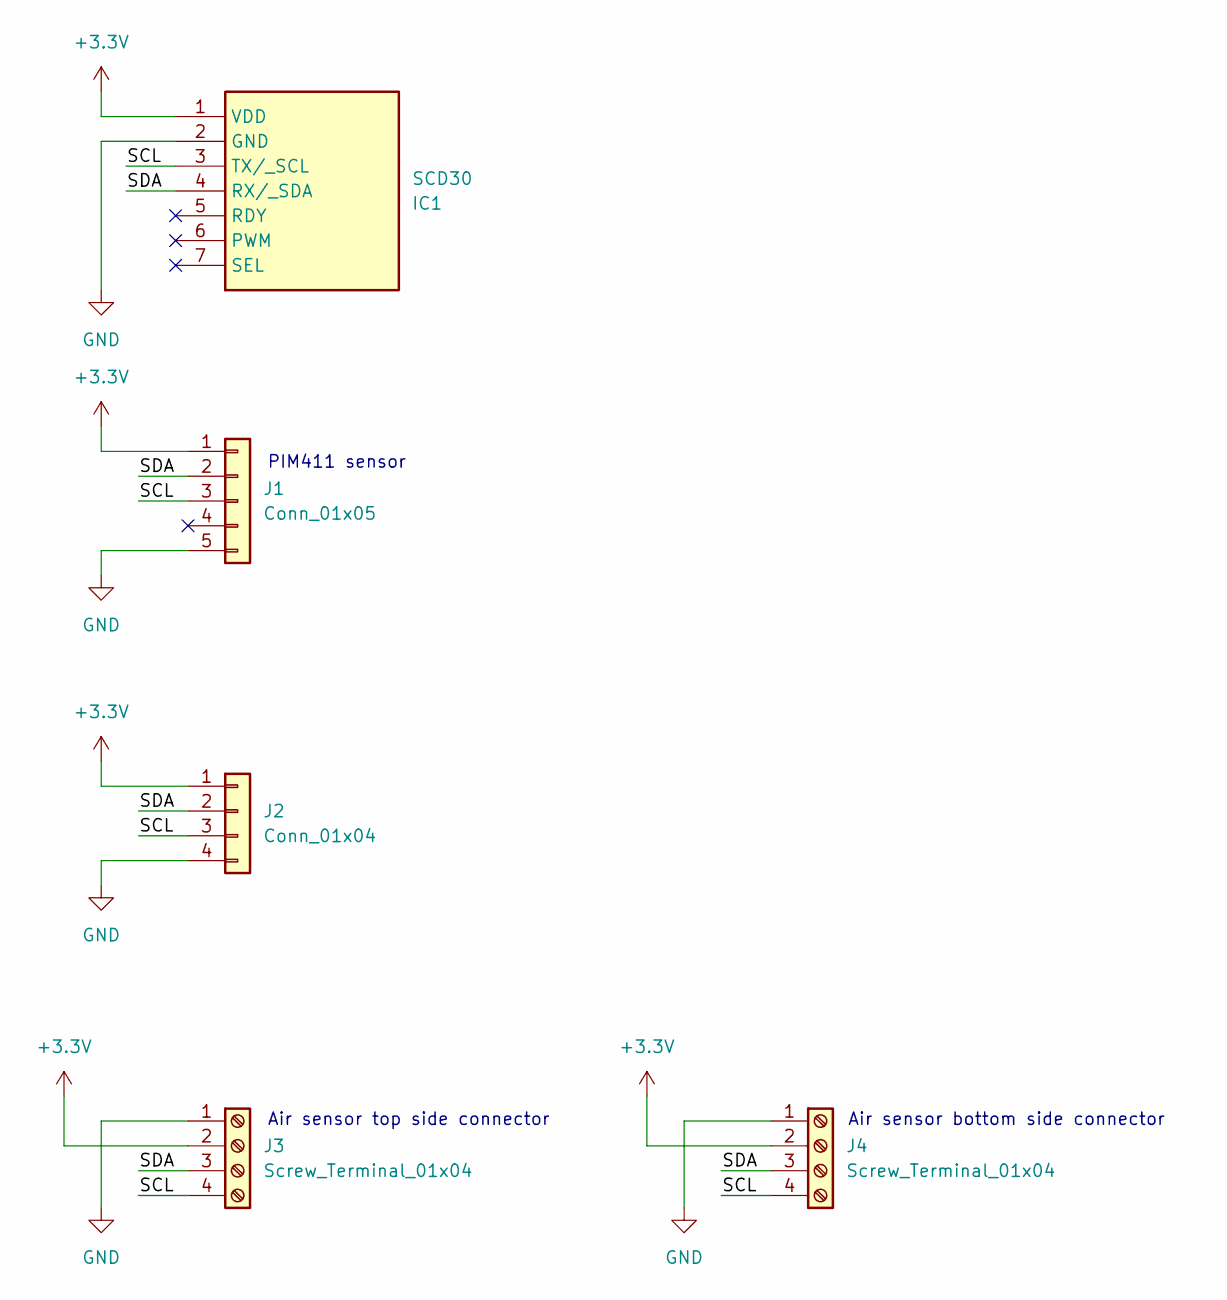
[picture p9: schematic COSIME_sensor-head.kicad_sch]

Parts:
IC1: SCD30; Manufacturer_Part_Number SCD30; Mouser Part Number 403-SCD30
J1: Conn_01x05; PinSocket_1x05_P2.54mm_Vertical
J2: Conn_01x04; PinSocket_1x04_P2.54mm_Vertical
J3, J4: Screw_Terminal_01x04; 1778719

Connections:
+3.3V: IC1.1 (VDD), J1.1, J2.1, J3.2, J4.2
/SCL: IC1.3 (TX/_SCL), J1.3, J2.3, J3.4, J4.4
/SDA: IC1.4 (RX/_SDA), J1.2, J2.2, J3.3, J4.3
GND: IC1.2 (GND), J1.5, J2.4, J3.1, J4.1

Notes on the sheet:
Air sensor top side connector
Air sensor bottom side connector
PIM411 sensor

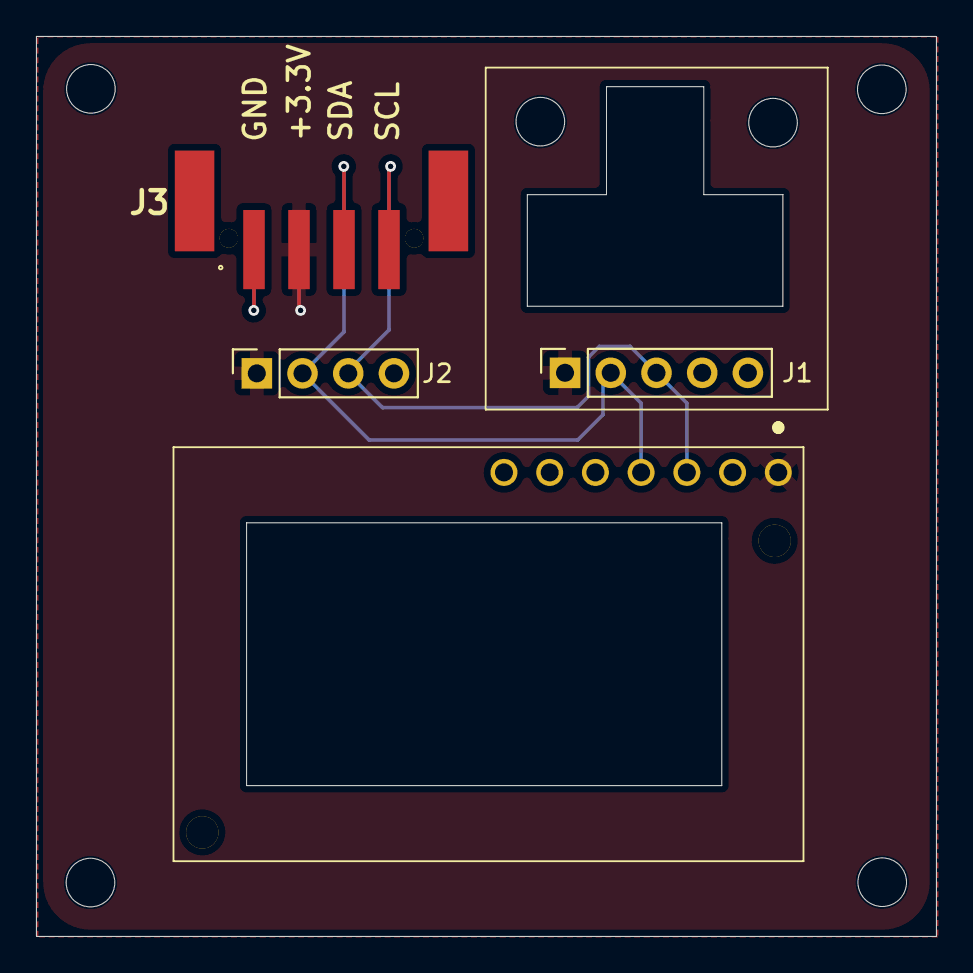
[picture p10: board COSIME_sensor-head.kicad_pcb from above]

Board: 2 copper layers, 50.0 x 50.0 mm, 5 parts (1 on the bottom side), 4 nets.

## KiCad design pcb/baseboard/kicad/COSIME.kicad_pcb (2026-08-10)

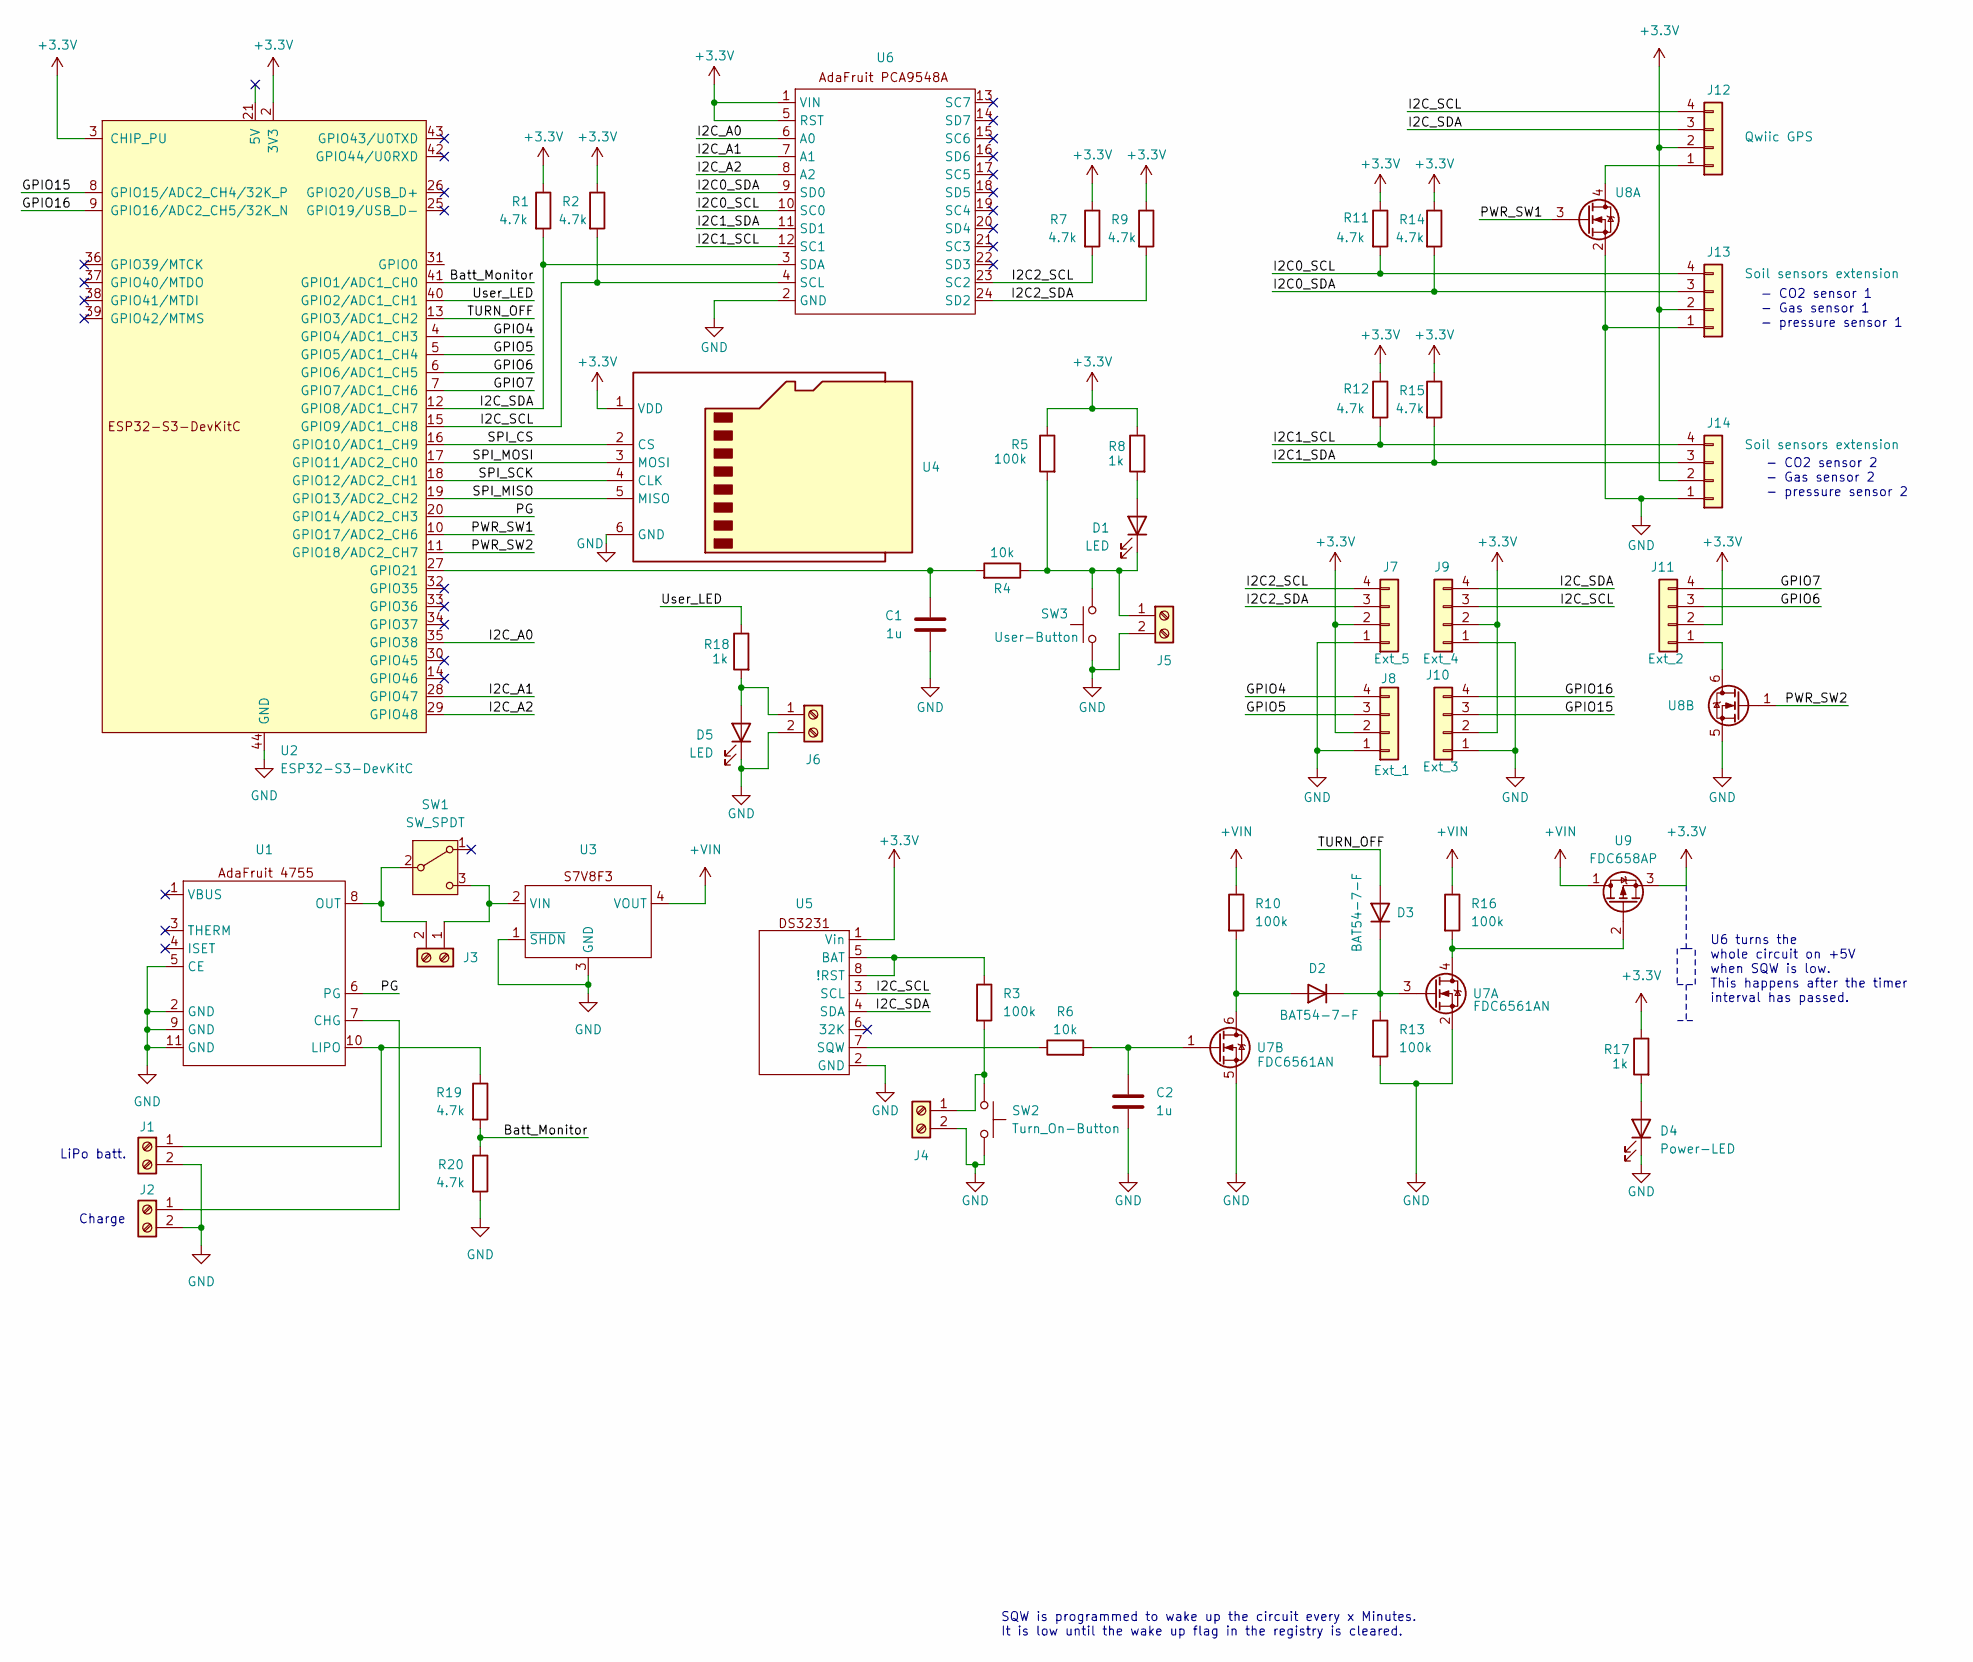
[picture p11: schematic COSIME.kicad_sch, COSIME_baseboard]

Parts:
C1, C2: 1u; C_0603_1608Metric_Pad1.08x0.95mm_HandSolder
D1, D5: LED; LED_0805_2012Metric_Pad1.15x1.40mm_HandSolder
D2, D3: BAT54-7-F; D_DO-35_SOD27_P7.62mm_Horizontal
D4: Power-LED; LED_0805_2012Metric_Pad1.15x1.40mm_HandSolder
J1, J2, J3, J4, J5, J6: Screw_Terminal_01x02; 1839198
J7: Ext_5; 1778719
J8: Ext_1; 1778719
J9: Ext_4; 1778719
J10: Ext_3; 1778719
J11: Ext_2; 1778719
J12: Qwiic GPS; 1778719
J13, J14: Soil sensors extension; 1778719
R1, R2, R7, R9, R11, R12, R14, R15, R19, R20: 4.7k; R_0603_1608Metric_Pad0.98x0.95mm_HandSolder
R3, R5, R10, R13, R16: 100k; R_0603_1608Metric_Pad0.98x0.95mm_HandSolder
R4, R6: 10k; R_0603_1608Metric_Pad0.98x0.95mm_HandSolder
R8, R17, R18: 1k; R_0603_1608Metric_Pad0.98x0.95mm_HandSolder
SW1: SW_SPDT; 500SSP1S2M2QEA
SW2: Turn_On-Button; SW_SPST_TL3305A
SW3: User-Button; SW_SPST_TL3305A
U1: 4755
U2: ESP32-S3-DevKitC
U3: Pololu_S7V8X
U4: MSD_BO1_SD-Card_Reader
U5: DS3231_Adafruit
U6: TCA9548A_AdaFruit
U7: FDC6561AN; SOT95P280X110-6N
U8: SOT95P280X110-6N
U9: FDC658AP; SOT95P275X110-6N_FDC658AP; Manufacturer_Part_Number FDC658AP; Mouser Part Number 512-FDC658AP

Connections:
+3.3V: J7.2, J8.2, J9.2, J10.2, J11.2, J12.2, J13.2, J14.2, R1.1, R2.1, R5.1, R7.1, R8.1, R9.1, R11.1, R12.1, R14.1, R15.1, R17.1, U2.1 (3V3), U2.2 (3V3), U2.3 (CHIP_PU), U4.1 (VDD), U5.1 (Vin), U6.1 (VIN), U6.5 (RST), U9.3
+VIN: R10.1, R16.1, U3.4 (VOUT), U9.1
/<NO NET>: J9.3, J12.4, R2.2, U2.15 (GPIO9/ADC1_CH8), U5.3 (SCL), U6.4 (SCL)
/Batt_Monitor: R19.2, R20.1, U2.41 (GPIO1/ADC1_CH0)
/GPIO4: J8.4, U2.4 (GPIO4/ADC1_CH3)
/GPIO5: J8.3, U2.5 (GPIO5/ADC1_CH4)
/GPIO6: J11.3, U2.6 (GPIO6/ADC1_CH5)
/GPIO7: J11.4, U2.7 (GPIO7/ADC1_CH6)
/GPIO15: J10.3, U2.8 (GPIO15/ADC2_CH4/32K_P)
/GPIO16: J10.4, U2.9 (GPIO16/ADC2_CH5/32K_N)
/I2C0_SCL: J13.4, R11.2, U6.10 (SC0)
/I2C0_SDA: J13.3, R14.2, U6.9 (SD0)
/I2C1_SCL: J14.4, R12.2, U6.12 (SC1)
/I2C1_SDA: J14.3, R15.2, U6.11 (SD1)
/I2C2_SCL: J7.4, R7.2, U6.23 (SC2)
/I2C2_SDA: J7.3, R9.2, U6.24 (SD2)
/I2C_A0: U2.35 (GPIO38), U6.6 (A0)
/I2C_A1: U2.28 (GPIO47), U6.7 (A1)
/I2C_A2: U2.29 (GPIO48), U6.8 (A2)
/I2C_SDA: J9.4, J12.3, R1.2, U2.12 (GPIO8/ADC1_CH7), U5.4 (SDA), U6.3 (SDA)
/PG: U1.6 (PG), U2.20 (GPIO14/ADC2_CH3)
/PWR_SW1: U2.10 (GPIO17/ADC2_CH6), U8.3
/PWR_SW2: U2.11 (GPIO18/ADC2_CH7), U8.1
/SPI_CS: U2.16 (GPIO10/ADC1_CH9), U4.2 (CS)
/SPI_MISO: U2.19 (GPIO13/ADC2_CH2), U4.5 (MISO)
/SPI_MOSI: U2.17 (GPIO11/ADC2_CH0), U4.3 (MOSI)
/SPI_SCK: U2.18 (GPIO12/ADC2_CH1), U4.4 (CLK)
/TURN_OFF: D3.2 (A), U2.13 (GPIO3/ADC1_CH2)
/User_LED: R18.1, U2.40 (GPIO2/ADC1_CH1)
GND: C1.2, C2.2, D4.1 (K), D5.1 (K), J1.2, J2.2, J4.2, J5.2, J6.2, J7.1, J8.1, J9.1, J10.1, J13.1, J14.1, R13.2, R20.2, SW2.2, SW3.2, U1.2 (GND), U1.5 (CE), U1.9 (GND), U1.11 (GND), U2.22 (GND), U2.23 (GND), U2.24 (GND), U2.44 (GND), U3.1 (~SHDN), U3.3 (GND), U4.6 (GND), U5.2 (GND), U6.2 (GND), U7.2, U7.5, U8.2, U8.5
unnamed: C2.1, R6.2, U7.1
unnamed: D1.2 (A), R8.2
unnamed: D1.1 (K), J5.1, R4.1, R5.2, SW3.1
unnamed: D2.2 (A), R10.2, U7.6
unnamed: D2.1 (K), D3.1 (K), R13.1, U7.3
unnamed: D4.2 (A), R17.2
unnamed: D5.2 (A), J6.1, R18.2
unnamed: J1.1, R19.1, U1.10 (LIPO)
unnamed: J2.1, U1.7 (CHG)
unnamed: J3.1, SW1.3 (C), U3.2 (VIN)
unnamed: J3.2, SW1.2 (B), U1.8 (OUT)
unnamed: J4.1, R3.2, SW2.1
unnamed: J11.1, U8.6
unnamed: J12.1, U8.4
unnamed: R16.2, U7.4, U9.2
unnamed: C1.1, R4.2, U2.27 (GPIO21)
unnamed: R3.1, U5.5 (BAT), U5.8 (!RST)
unnamed: R6.1, U5.7 (SQW)

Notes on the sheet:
U6 turns the whole circuit on +5V when SQW is low. This happens after the timer interval has passed.
SQW is programmed to wake up the circuit every x Minutes. It is low until the wake up flag in the registry is cleared.
LiPo batt.
Charge
- CO2 sensor 1 - Gas sensor 1 - pressure sensor 1
- CO2 sensor 2 - Gas sensor 2 - pressure sensor 2

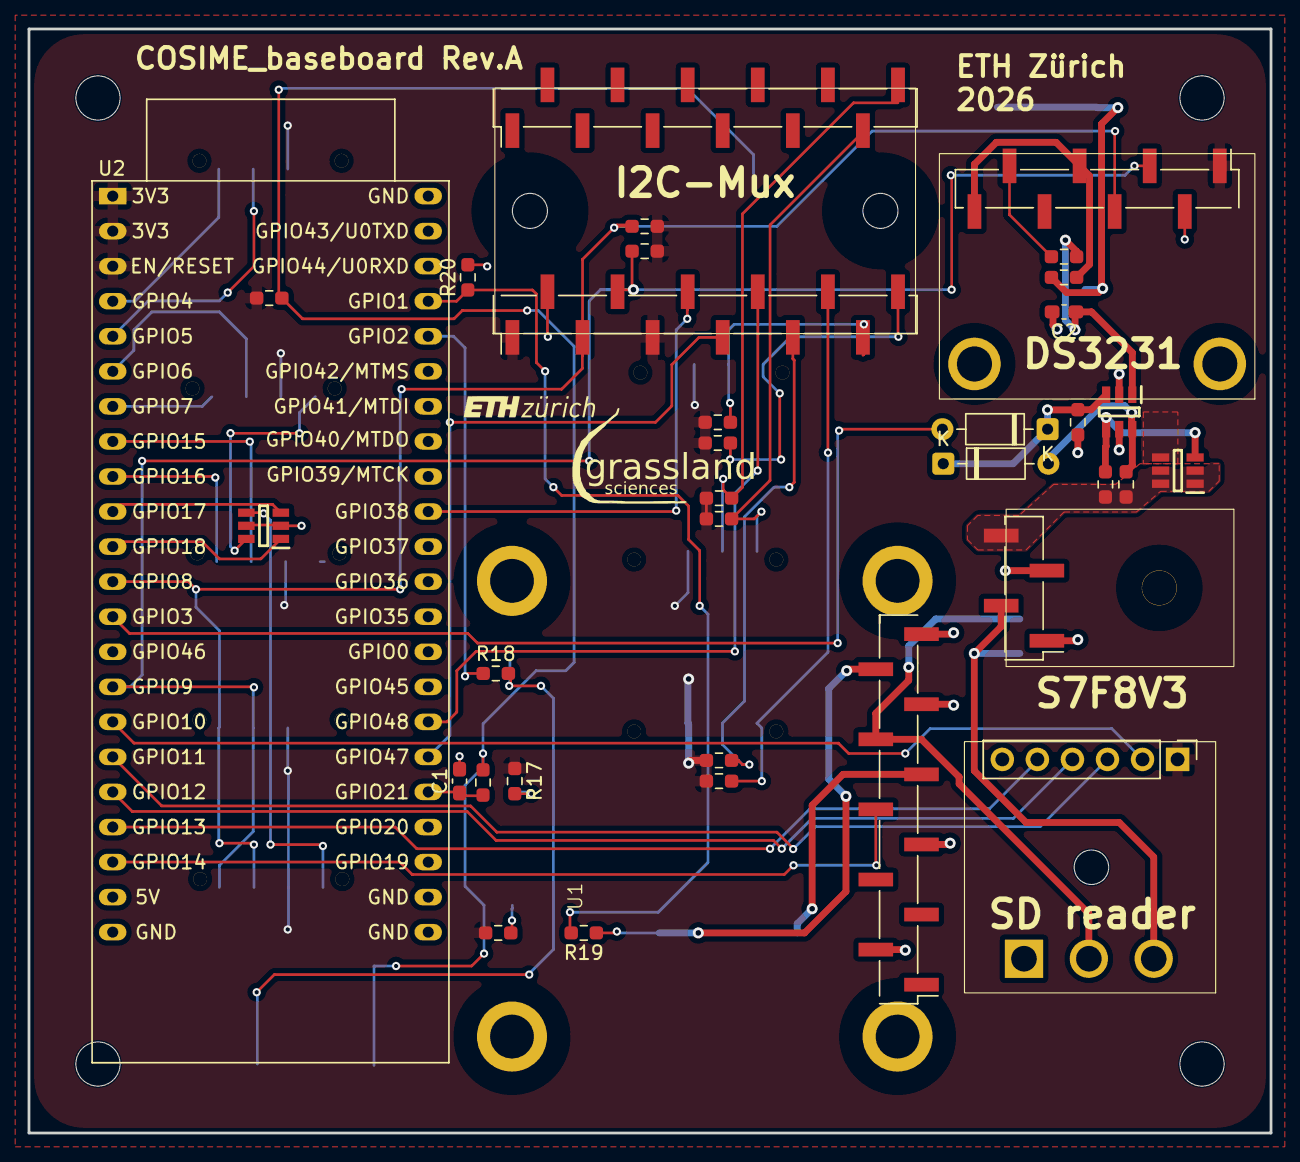
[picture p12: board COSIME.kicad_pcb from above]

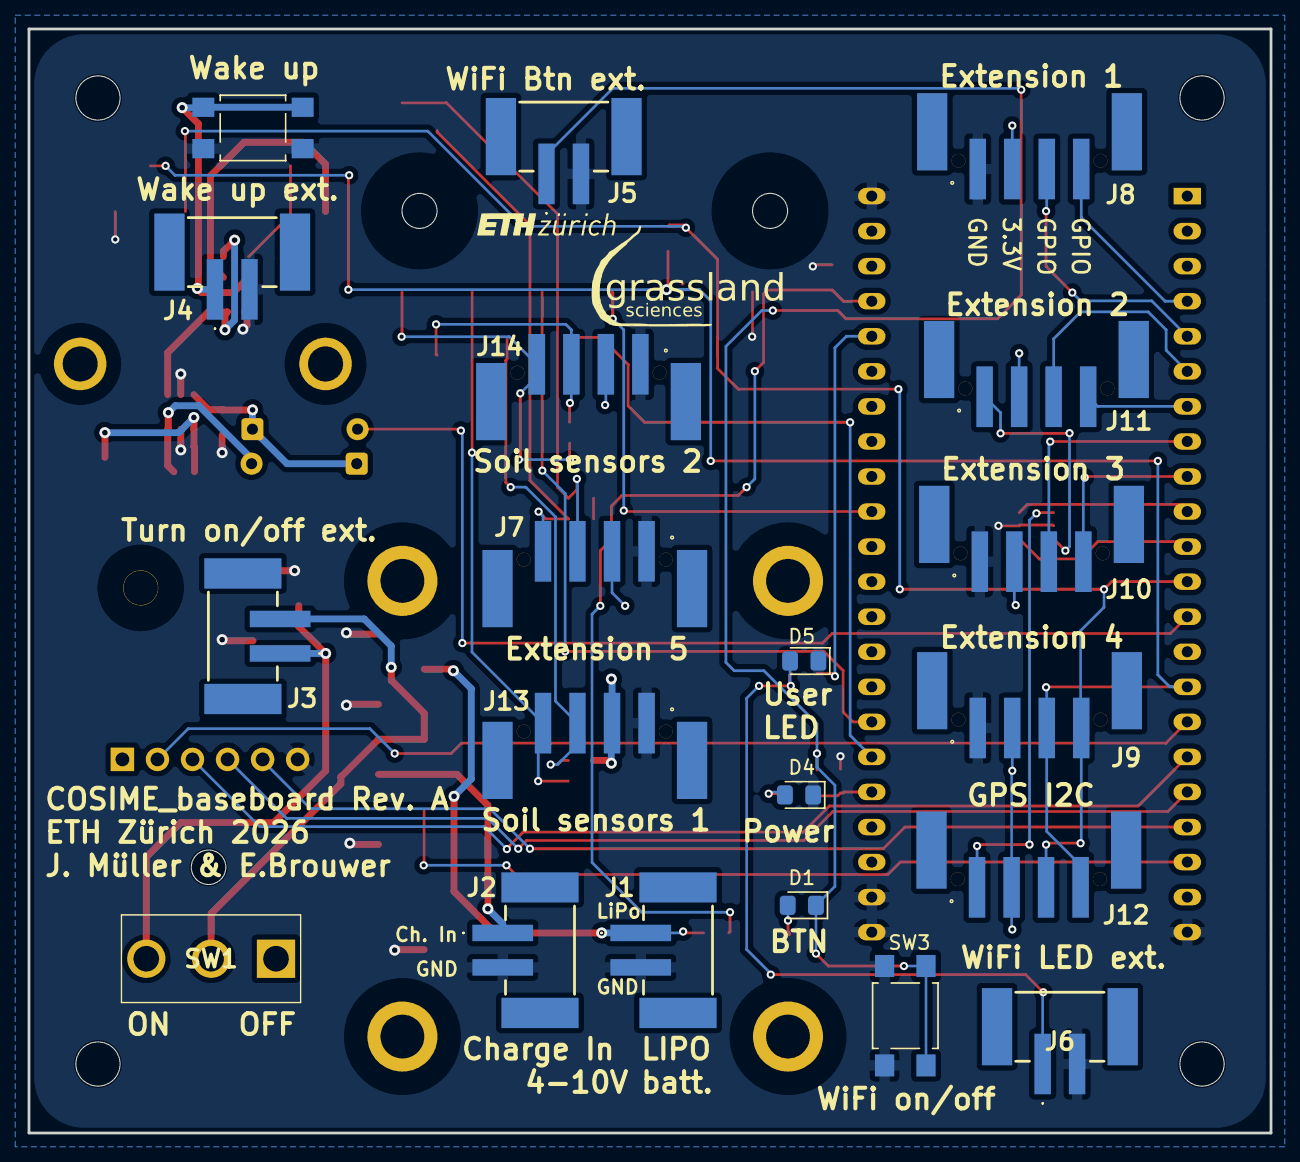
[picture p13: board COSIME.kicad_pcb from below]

Board: 2 copper layers, 90.0 x 80.0 mm, 53 parts (20 on the bottom side), 48 nets.

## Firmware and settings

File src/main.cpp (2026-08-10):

// ============================================================================
//                        DATALOGGER  —  CONFIGURATION
//
//  Edit only the values in this block, then upload. Everything else lives in
//  the framework (datalogger.h) and does not need to be touched.
// ============================================================================

// --- How often to record a measurement (in seconds) ---
#define SAMPLE_INTERVAL_SECONDS   20

// --- WiFi -------------------------------------------------------------------
//  1 = the logger makes its own WiFi hotspot; open the dashboard by joining it
//      (works in the field, no router needed). This is the default.
//  0 = the logger joins your existing WiFi. If you choose 0, un-comment and
//      fill in WIFI_SSID / WIFI_PASS below.
#define WIFI_ACCESS_POINT_MODE    1
// #define WIFI_SSID   "MyNetwork"
// #define WIFI_PASS   "MyPassword"

// --- Passwords --------------------------------------------------------------
#define HOTSPOT_PASSWORD      "datalogger"   // WiFi password in access-point mode
#define DASHBOARD_USER        "admin"        // web dashboard login name
#define DASHBOARD_PASSWORD    "datalogger"   // web dashboard login password

// --- Single-instance parts (1 = yes, 0 = no) --------------------------------
#define ENABLE_MICROSD     1   // MicroSD card logging
#define ENABLE_BATTERY     1   // battery voltage / charge reading
#define ENABLE_GPS         1   // GPS module (date, time, location)
#define ENABLE_CALIBRATION 1   // sensor calibration + web calibration interface

// --- Calibration ------------------------------------------------------------
// While a calibration session is open, calibrating changes values in memory
// only - they are all saved together the moment you close it (this spares the
// memory chip, which wears out if written to too often). If a session is left
// open and untouched for this many minutes, it saves itself so the work is not
// lost. Set to 0 to never save automatically.
#define CALIBRATION_TIMEOUT_MINUTES  30

// --- Sensors on the I2C multiplexer -----------------------------------------
// For each sensor type, list the multiplexer channel(s) it is wired to. You may
// run two of the same type on two different channels (e.g. a reference and a
// field sensor, which the differential calibration compares). Comment a line
// out to disable that sensor type entirely.
//   * Max 2 channels per type (differential calibration compares 2 sensors).
//   * Channels may be any TCA9548A channel number (0-7), e.g. "0, 2".
#define BME280_BUSES     0, 1   // air temperature / humidity / pressure
#define SCD30_BUSES      0, 1   // CO2
#define SEN0465_BUSES    0, 1   // O2
// #define MLX90614_BUSES   0   // infrared / thermal (off)
// #define ADS1115_BUSES    0   // analog-to-digital converter (single channel only)

// Note: the multiplexer itself (I2C_MULTI) is configured in src/config.h,
// because the sensor libraries must be compiled with the same setting.
// ============================================================================
//                          END OF CONFIGURATION
// ============================================================================

#include <datalogger.h>

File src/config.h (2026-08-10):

#pragma once
#include <string>

// ============================================================================
//  ADVANCED settings — shared with the sensor libraries (lib/) and config.cpp,
//  so they must live here rather than in main.cpp. Most users never edit this
//  file. The everyday configuration (sampling rate, WiFi, which sensors are
//  connected) is at the top of main.cpp.
// ============================================================================

#ifndef H4P_SECURE
#define H4P_SECURE 1
#endif

// Optional radios / network clients (off by default). These are read here and
// in config.cpp, so they stay in this shared header.
#define USE_MQTT 0
#define USE_HTTPREQ 0
#define USE_BLESERVER 0
#define USE_BLECLIENT 0

#define SECURE_MQTT 1
#define SECURE_WEBSERVER 0
#define SECURE_HTTPREQ 1

// Firmware version string (shown on the serial console at boot).
#define WS_VERSION "0.5"

// ---------------------------------------------------------------------------
//  I2C bus topology. I2C_MULTI selects single-bus vs dual-bus (TCA9548A
//  multiplexer) wiring. This MUST be set here: the sensor libraries in lib/
//  are compiled separately and change their layout based on it, so it cannot
//  be moved into main.cpp.
// ---------------------------------------------------------------------------
#define I2C_MULTI    1
#if I2C_MULTI
#define I2C_BUS0     0
#define I2C_BUS1     0
#define I2C_BUS2     1
#define I2C_BUS3     1
#endif

// ESP8266/RP2040 don't support TLS
#if defined(ARDUINO_ARCH_ESP8266) || defined(ARDUINO_ARCH_RP2040)
#undef H4P_SECURE
#undef SECURE_WEBSERVER
#undef SECURE_HTTPREQ
#define H4P_SECURE 		0
#define SECURE_WEBSERVER 0
#define SECURE_HTTPREQ  0
#endif

#if !(ARDUINO_ARCH_ESP32 && CONFIG_BT_ENABLED && CONFIG_BT_BLUEDROID_ENABLED) // !H4P_BLE_AVAILABLE
#undef USE_BLECLIENT
#undef USE_BLESERVER
#define USE_BLECLIENT 	0
#define USE_BLESERVER 	0
#endif

#if USE_HTTPREQ
#if SECURE_HTTPREQ && !H4P_SECURE
#warning "Activate H4P_SECURE if attempting to secure the HTTP requests"
#undef SECURE_HTTPREQ
#define SECURE_HTTPREQ 0
#endif
#endif

#if SECURE_WEBSERVER && !H4P_SECURE
#warning "Activate H4P_SECURE if attempting to secure the webserver"
#undef SECURE_WEBSERVER
#define SECURE_WEBSERVER 0
#endif

#if SECURE_MQTT && !H4P_SECURE
#warning "Activate H4P_SECURE if attempting to secure the MQTT Client"
#undef SECURE_MQTT
#define SECURE_MQTT 0
#endif

#if USE_MQTT
extern const char *MQTT_SERVER;
#if SECURE_MQTT
extern std::string MQTT_CERT;
#endif // H4P_SECURE
#endif // USE_MQTT

#if SECURE_WEBSERVER
extern std::string WEBSERVER_CERT;
extern std::string WEBSERVER_PRIV_KEY;
#endif // SECURE_WEBSERVER

#if USE_HTTPREQ && SECURE_HTTPREQ
// ISRG Root X1 certificate, the CA of Let's Encrypt
extern std::string test_root_ca;
#endif // SECURE_HTTPREQ

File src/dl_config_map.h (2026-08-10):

#pragma once
// ============================================================================
//  Config translation layer.
//
//  Turns the friendly settings a beginner writes at the top of main.cpp into
//  the internal macro names the framework uses, and supplies sensible defaults
//  for anything left unset (so an empty config still builds and runs).
//
//  You should not need to edit this file. To change what the logger does, edit
//  the configuration block in main.cpp. Advanced hardware options (I2C bus
//  topology, radios, TLS) live in config.h.
// ============================================================================

// ---------------------------------------------------------------- Sampling --
#ifdef SAMPLE_INTERVAL_SECONDS
  #define MEASUREMENT_INTERVAL SAMPLE_INTERVAL_SECONDS
#endif
#ifndef MEASUREMENT_INTERVAL
  #define MEASUREMENT_INTERVAL 20
#endif

// -------------------------------------------------------------------- WiFi --
// 1 = the logger runs its own access point (offline dashboard, no router).
// 0 = the logger joins an existing network (define WIFI_SSID / WIFI_PASS).
//
// These two are the exception to the pattern used everywhere else in this file.
// H4Plugins compiles its own .cpp files as separate translation units that
// never include a project header, and H4P_USE_WIFI_AP guards a data member of
// class H4P_WiFi as well as whole functions. Defining it only here would give
// the project and the library two different layouts for the same class, and the
// access point would never start because _startAP() was never compiled at all.
//
// scripts/project_defines.py therefore reads WIFI_ACCESS_POINT_MODE and
// HOTSPOT_PASSWORD out of main.cpp and passes them as global -D flags, so both
// halves of the build agree. The guards below defer to that, and only supply a
// value when this header is used without the pre-build script.
#ifndef H4P_USE_WIFI_AP
  #ifdef WIFI_ACCESS_POINT_MODE
    #define H4P_USE_WIFI_AP WIFI_ACCESS_POINT_MODE
  #else
    #define H4P_USE_WIFI_AP 1
  #endif
#endif

// Access-point WiFi password
#ifndef DATALOGGER_AP_PASSWORD
  #ifdef HOTSPOT_PASSWORD
    #define DATALOGGER_AP_PASSWORD HOTSPOT_PASSWORD
  #else
    #define DATALOGGER_AP_PASSWORD "datalogger"
  #endif
#endif

// Web dashboard login
#ifdef DASHBOARD_USER
  #define DATALOGGER_UI_USER DASHBOARD_USER
#endif
#ifndef DATALOGGER_UI_USER
  #define DATALOGGER_UI_USER "admin"
#endif
#ifdef DASHBOARD_PASSWORD
  #define DATALOGGER_UI_PASSWORD DASHBOARD_PASSWORD
#endif
#ifndef DATALOGGER_UI_PASSWORD
  #define DATALOGGER_UI_PASSWORD "datalogger"
#endif

// ------------------------------------------------------ Sensors / hardware --
#ifdef ENABLE_MICROSD
  #define USE_MICROSD ENABLE_MICROSD
#endif
#ifndef USE_MICROSD
  #define USE_MICROSD 1
#endif

#ifdef ENABLE_BATTERY
  #define USE_BATTERY ENABLE_BATTERY
#endif
#ifndef USE_BATTERY
  #define USE_BATTERY 1
#endif

#ifdef ENABLE_GPS
  #define USE_GPS ENABLE_GPS
#endif
#ifndef USE_GPS
  #define USE_GPS 1
#endif

// Multiplexer sensor types are enabled by listing their bus(es) in main.cpp
// (e.g. #define BME280_BUSES 0, 1). Presence of the *_BUSES macro turns the
// type on; the bus list itself is consumed later in dl_objects.h.
#ifdef BME280_BUSES
  #define USE_BME280 1
#else
  #define USE_BME280 0
#endif

#ifdef SCD30_BUSES
  #define USE_SCD30 1
#else
  #define USE_SCD30 0
#endif

#ifdef SEN0465_BUSES
  #define USE_SEN0465 1
#else
  #define USE_SEN0465 0
#endif

#ifdef MLX90614_BUSES
  #define USE_MLX90614 1
#else
  #define USE_MLX90614 0
#endif

#ifdef ADS1115_BUSES
  #define USE_ADS1115 1
#else
  #define USE_ADS1115 0
#endif

// --------------------------------------------------------------- Calibration --
#ifdef ENABLE_CALIBRATION
  #define USE_CAL ENABLE_CALIBRATION
#endif
#ifndef USE_CAL
  #define USE_CAL 1
#endif

// How long a calibration may sit switched on and untouched before it saves
// itself, in minutes. 0 = never save automatically.
#ifdef CALIBRATION_TIMEOUT_MINUTES
  #define CAL_SESSION_TIMEOUT_MIN CALIBRATION_TIMEOUT_MINUTES
#endif
#ifndef CAL_SESSION_TIMEOUT_MIN
  #define CAL_SESSION_TIMEOUT_MIN 30
#endif

// Environmental physics helpers are on by default and are REQUIRED whenever
// calibration is enabled (calibration converts humidity <-> mole fraction).
#ifndef USE_ENV
  #define USE_ENV 1
#endif
#if USE_CAL && !USE_ENV
  #undef USE_ENV
  #define USE_ENV 1
#endif

// -------------------------------------------------------------- Diagnostics --
// Built-in self-test routine (developers only); off unless explicitly enabled.
#ifndef RUN_TEST
  #define RUN_TEST 0
#endif

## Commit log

2025-06-28 Work on physics and sensors
    - Added environmental library (physics)
    - Remove SO-411 (non-functional)
    - Add testing routine for various tests
    - Minor changes to SD card, MLX90614 & GPS
    - Minor changes to BME280
2025-06-28 Support for multiple i2c buses
2025-07-02 Implement O2 sensor
2025-07-02 Add O2 sensor and reorganise
2025-07-02 Add all sensors on both buses
2025-07-02 Rename battery library
2025-08-27 Update buttons
2025-09-04 Add preliminary calibration logic
2025-09-08 Added calibration logic
2025-09-08 Update calibration logic
2025-10-03 Improved calibration functionality
2025-10-03 Multiplexer, new buttons, calibration, etc
    Implement all changes from other sub-libraries
2025-10-17 Asynchronous calibration loop
    This is a major rewrite of the code base
2025-11-20 Switch BME280 lib & fix O2 units
    [main.cpp]
2025-11-21 Added calibration via Serial port
2025-11-24 Show all calibrations logic
2026-02-13 Massive calibration update
2026-02-13 Integrate calibration logic
2026-05-29 Add image from prototype testing
2026-06-03 Add preliminary data
    [calibration_20250925.csv, calibration_20251003.csv, calibration_20251016.csv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]
2026-06-11 Added new data
    [data_20260603.csv, data_20260607.csv, status_20260603.csv]
2026-06-18 New data
    [data_20260611.csv, data_20260612.csv, data_20260613.csv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]
2026-06-29 Improve analysis notebooks
    [data_20260618.csv, data_20260619.csv, data_20260620.csv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]
2026-07-10 Add new data
    [data_20260626.csv, data_20260627.csv, data_20260629.csv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]
2026-07-15 Test changes
    [data_20260708.csv, data_20260709.csv, data_20260710.csv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]
2026-08-10 Add KiCad files
    [COSIME.kicad_pcb, COSIME.kicad_sch]
2026-08-10 add electrical and manufacturing doc
    [COSIME_BOM.csv]

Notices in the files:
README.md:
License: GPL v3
